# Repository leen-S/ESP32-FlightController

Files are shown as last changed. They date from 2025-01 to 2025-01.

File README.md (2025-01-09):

# ESP32 Flight Controller

## Overview

This repository contains all the necessary files for the **ESP32 Flight Controller** project. Designed for educational and practical purposes, this project showcases how an ESP32 microcontroller can be used to develop a flight controller. It includes firmware, schematics, PCB designs, and manufacturing files to bring the project to life.

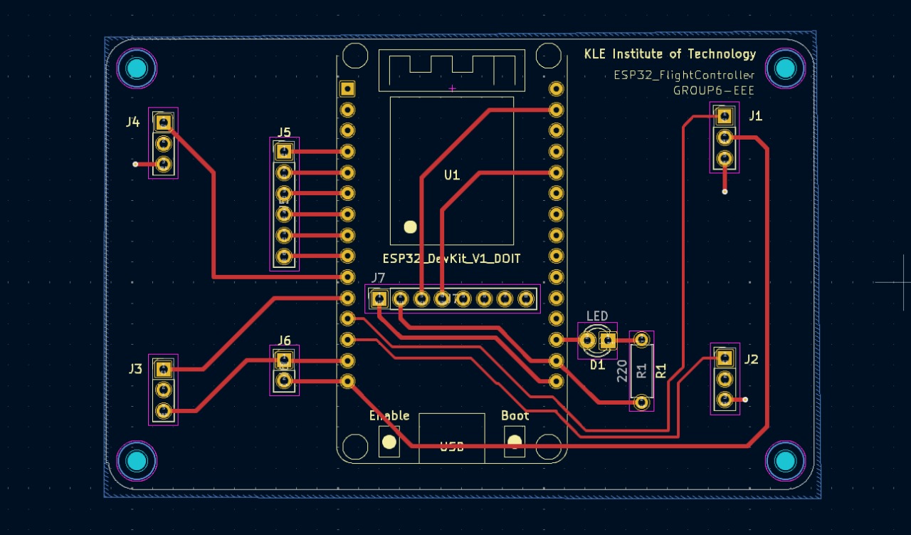
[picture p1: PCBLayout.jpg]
image alt

---

## Repository Structure

### 1. **ESP32-Flight-Controller--main**
This folder contains:
- **Code**: The firmware written for the ESP32 microcontroller to manage and control the drone's operations.
- **Schematics**: Circuit diagrams detailing the hardware connections and design.

### 2. **PCB Designs/KiCAD**
This folder contains:
- **Sketches**: Conceptual sketches of the PCB layout.
- **PCB Layout**: The complete PCB design created using KiCAD.
- **Manufacturing and Gerber Files**: Files required for manufacturing the PCB, including drill files, silkscreen layers, and solder masks.

---

## How to Use

### 1. **Setup and Prerequisites**
- Install the necessary tools:
  - Arduino IDE (or PlatformIO) for uploading the firmware.
  - KiCAD for viewing and editing PCB designs.
- Ensure you have an ESP32 Dev Kit and other necessary components as specified in the schematics.

### 2. **Firmware Installation**
- Navigate to the `ESP32-Flight-Controller--main` folder.
- Open the provided `.ino` or equivalent firmware file in your IDE.
- Configure the project-specific parameters (e.g., pin mappings and calibration values).
- Upload the firmware to the ESP32 using a USB connection.

### 3. **PCB Manufacturing**
- Navigate to the `PCB Designs/KiCAD` folder.
- Use the Gerber files to manufacture the PCB:
  - Upload them to a PCB manufacturer (e.g., JLCPCB, PCBWay).
- Assemble the components as per the provided schematics.

---

## Features
- **ESP32-based Control**: Utilizes the ESP32 microcontroller for real-time flight control.
- **Modular Design**: The project is organized into distinct files for ease of use and modification.
- **Custom PCB**: Designed using KiCAD for a compact and efficient layout.
- **Open Source**: Fully customizable and adaptable for different applications.

---

## Acknowledgment
Special thanks to **@pratikphadte** for making amazing videos.

---

## Contributing
Contributions are welcome! Feel free to:
- Submit bug reports or feature requests via the Issues tab.
- Fork the repository and submit pull requests with improvements.

---

## License
This project is licensed under the [MIT License](LICENSE). You are free to use, modify, and distribute the code and designs with proper attribution.

---

## Contact
For questions or collaboration, reach out via:
- **Email**: neelalohitk@gmail.com
- **LinkedIn**: https://www.linkedin.com/in/neelalohit-korlhalli/

---

Happy Building! 🚀

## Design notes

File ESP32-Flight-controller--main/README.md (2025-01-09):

# ESP32 Flight Controller  

I have chosen ESP32 as a flight controller mainly because of its cost, WiFi & BLE capabilities. Which one can exploit to integrate with ROS. 
---

## Watch Tutorial videos
#### Dorm Flight  
Dorm flight (https://youtu.be/2goVaf8LJQM)

#### Flight Demonstration & few guidelines before building
Flight Demonstration (https://youtu.be/PweCWXNrxg0?si=KJHE-g0SIH3p4Ixf)

#### Understanding PID Controller  
Understanding PID Controller (https://youtu.be/dMRDzicSvXk?si=4SlX_EvzxvCbH7zv)

#### Tuning of PID Controller Gains via ESP32 Webserver WiFi  
Tuning of PID Controller Gains (https://youtu.be/kl3Dlm11AEQ?si=NrJVn8WFx9-ViMtl)

---

## Testing  

Before attempting flight, ensure all components are functioning correctly by testing them individually using the codes provided in the **testing folder**:  

- Use **/ESP32-Flight-controller-/test/reciever_pwm_esp32/reciever_pwm_esp32.ino** to verify the signals from the receiver and transmitter.  
- Use **/ESP32-Flight-controller-/test/measure_angles_from_mpu/measure_angles_from_mpu.ino** to confirm the IMU is measuring angles accurately.  
- Use **/ESP32-Flight-controller-/test/motor_calibration_esp32/motor_calibration_esp32.ino** to calibrate all ESCs and ensure motors are properly synchronized.  
- Use **/ESP32-Flight-controller-/test/Voltage_measurement_esp32/Voltage_measurement_esp32.ino** to validate the voltage sensing circuit. This part is not yet impleneted in the main Flight controller (Can be skipped).

- Use **/workspaces/ESP32-Flight-controller-/test/anglemode_flightcontroller_ver3.1_PID_values_tuning_webserver/anglemode_flightcontroller_ver3.1_PID_values_tuning_webserver.ino** to tune the PID gains of your drone. Do this step when you have calibrated your drone and ensured proper motor direction, propeller direction is as per the hand drawn cirucit diagram in **/ESP32-Flight-controller-/resources/Circuit diagram _HANDDRAWN_ only IMU_01.pdf**

---

## Flying  

Before flying the drone, follow these steps:  

1. **IMU Calibration**  
   - Run the calibration code from the **/ESP32-Flight-controller-/src/Gyro_accelerometer_calibration.ino** to calibrate the IMU. Ensure the quadcopter is on a level surface during this process.  
   - Record the calibrated values generated by the calibration code, check the serial monitor.

2. **Update the Main Flight Code**  
   - Enter the calibrated IMU values into the **/ESP32-Flight-controller-/src/Anglemode_flightcontroller_ver3.1.ino** code's void Setup() with these values before uploading it to the ESP32.  

3. **Tune PID gains** 
    - Refer the PID tuning video in the above YT links and tune your quadcopter, refer the **/ESP32-Flight-controller-/test/anglemode_flightcontroller_ver3.1_PID_values_tuning_webserver/anglemode_flightcontroller_ver3.1_PID_values_tuning_webserver.ino** code for seamless WIFI pid gains tuning. For a F450 frame the PID values should be more or less the same as the values in the original code. For other drone frames it might varry in a slight manner.

3. **Prepare for Flight**  
   - Double-check motor rotations and propeller    orientations as per the schematic.  
   - Ensure all connections are secure.  

5. **Safety First!!!!**
    -The quadcopter motors and propellers possess significant destructive energy. Always:  
    - Conduct initial tests outdoors.  
    - Verify that all propellers are installed in the correct direction and that motor rotations match the schematic.  
    - Recheck motor and propeller functionality before uploading the main flight code.  

5. **You're Ready to fly!**
    - Perform an initial outdoor test for safety.  

---

## References
- [Joop Brooking](https://www.youtube.com/@Joop_Brokking)  
- [Carbon Aeronautics](https://youtube.com/@carbonaeronautics?si=-DZ1Sz5sgNruoJgR)

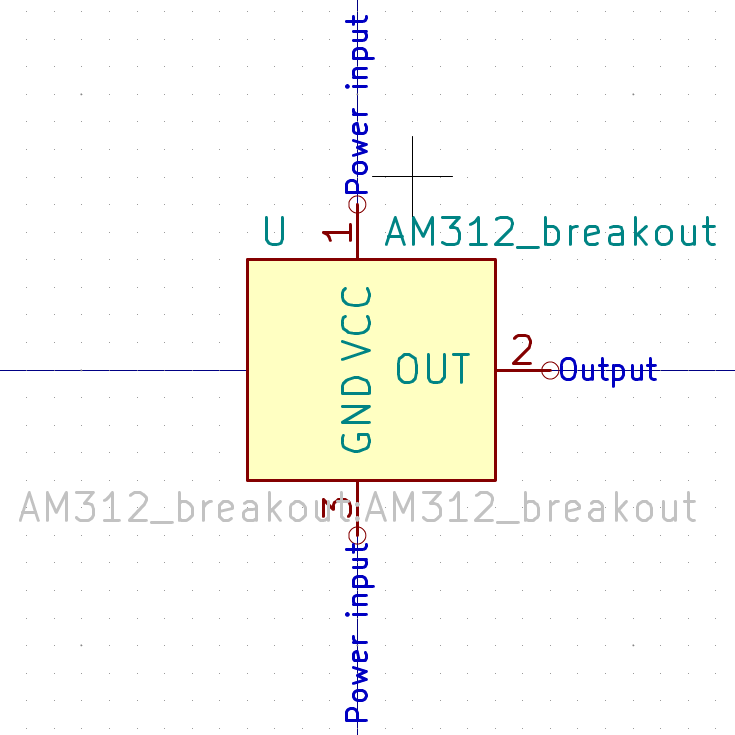
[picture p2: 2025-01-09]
PCB Designs/KiCAD/kicad-master/kicad-master/documentation/aht10_breakout/images/symbol.png

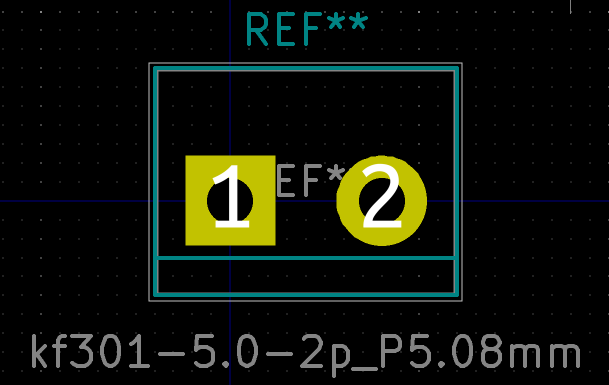
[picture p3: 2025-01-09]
PCB Designs/KiCAD/kicad-master/kicad-master/documentation/kf301_5.0/images/footprint.png

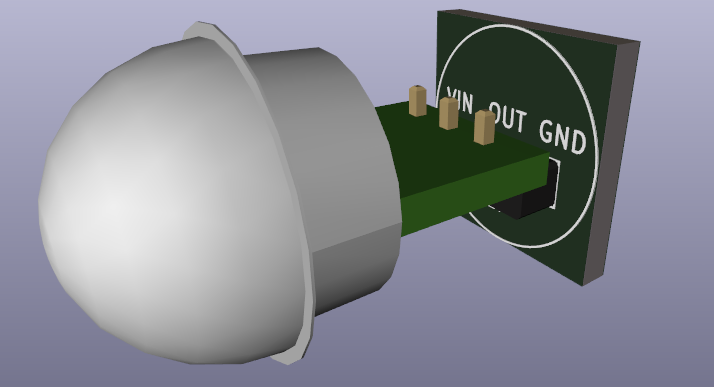
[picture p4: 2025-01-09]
PCB Designs/KiCAD/kicad-master/kicad-master/documentation/am312_breakout/images/3d_view.png

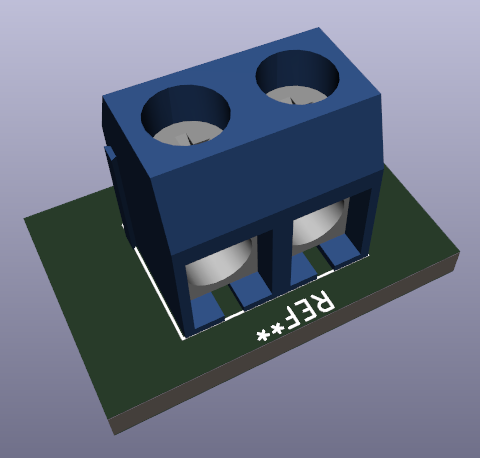
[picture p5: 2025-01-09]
PCB Designs/KiCAD/kicad-master/kicad-master/documentation/kf301_5.0/images/3d_view.png

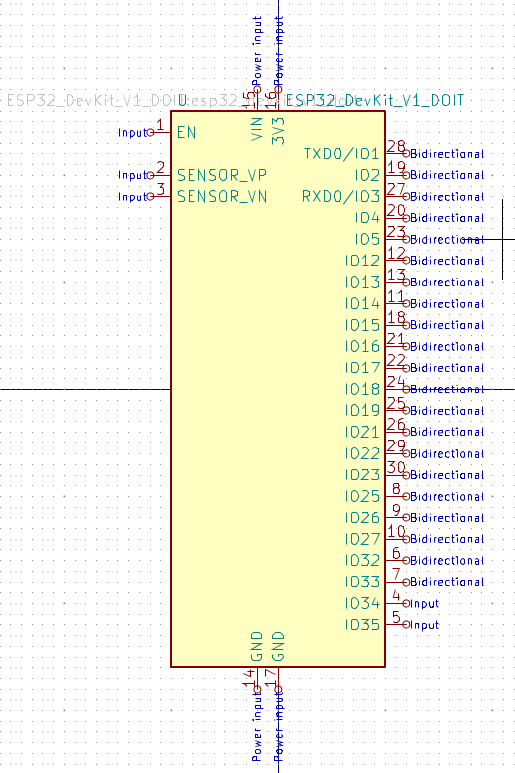
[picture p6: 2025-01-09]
PCB Designs/KiCAD/kicad-master/kicad-master/documentation/esp32_devkit_v1_doit/images/symbol.png

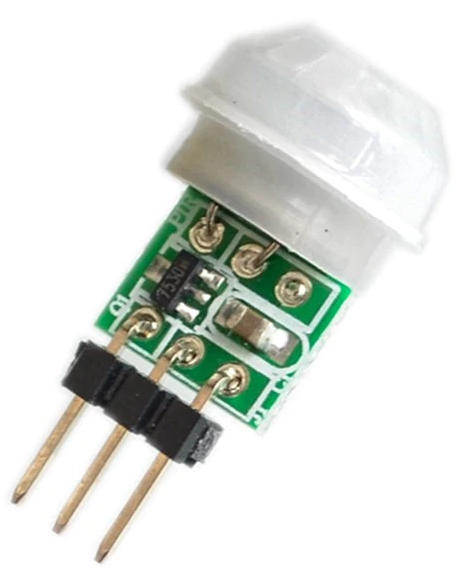
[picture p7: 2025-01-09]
PCB Designs/KiCAD/kicad-master/kicad-master/documentation/am312_breakout/images/picture.jpg

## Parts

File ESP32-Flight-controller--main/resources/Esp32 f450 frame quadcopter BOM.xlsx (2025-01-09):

ESP32 QUADCOPTER BILL OF MATERIALS
Sr No | Category | Item Desc | Qty Reqd | Unit Price(INR) | Total price(INR) | Total Quadcopter Cost(Excluding tools) | 11675
1 | Quadcopter | F450 / Q450 Quadcopter Frame – PCB Version Frame Kit with Integrated PCB – Made in INDIA | 1 | 800 | 800 | Flight contorller cost | 685
2 | Quadcopter | Flysky FS-i6X 2.4GHz 6CH AFHDS 2A RC Transmitter With FS-iA10B 2.4GHz 10CH Receiver | 1 | 4800 | 4800
3 | Quadcopter | A2212 1000 KV BLDC Brushless DC Motor with SimonK 30A ESC | 4 | 710 | 2840
4 | Quadcopter | Orange HD Propellers 8045(8X4.5) ABS Black 1CW+1CCW-1pair | 3 | 100 | 300
5 | Quadcopter | Orange 11.1V 2200mAh 40C 3S Lithium Polymer Battery Pack | 1 | 1800 | 1800
6 | Quadcopter | Lipo Battery Charger | Battery Balancer Charger 7.4-11.1V RC Pro Compact Charger B3AC | 1 | 450 | 450
7 | Flight controller | MPU-6050 3-Axis Accelerometer and Gyro Sensor | 1 | 115 | 115
8 | Flight controller | ESP32 DEV KIT DO IT 1 | 1 | 400 | 400
9 | Flight controller | 5 x 7 cm Universal PCB Prototype Board | 1 | 30 | 30
10 | Flight controller | LED | 1 | 10 | 10
11 | Flight controller | Resistors 220 ohms | 1 | 10 | 10
12 | Flight controller | Single strand wire (1m) | 1 | 40 | 40
13 | Flight controller | Berg pin male strip | 2 | 20 | 40
14 | Flight controller | Berg pin female strip | 2 | 20 | 40
15 | Tools & adhesives | Soldering Iron | 1 | 300 | 300
16 | Tools & adhesives | Soldering wire | 1 | 50 | 50
17 | Tools & adhesives | Soldering flux | 1 | 20 | 20
18 | Tools & adhesives | Double sided tape roll | 1 | 50 | 50
19 | Tools & adhesives | Zipties (15cm long) packet | 1 | 60 | 60
20 | Tools & adhesives | Wire cutter | 1 | 50 | 50
21 | Tools & adhesives | Insulation tape | 1 | 20 | 20
22 | Tools & adhesives | Allen Key for M2,M3 & M4 Grub Screw | 1 | 40 | 40

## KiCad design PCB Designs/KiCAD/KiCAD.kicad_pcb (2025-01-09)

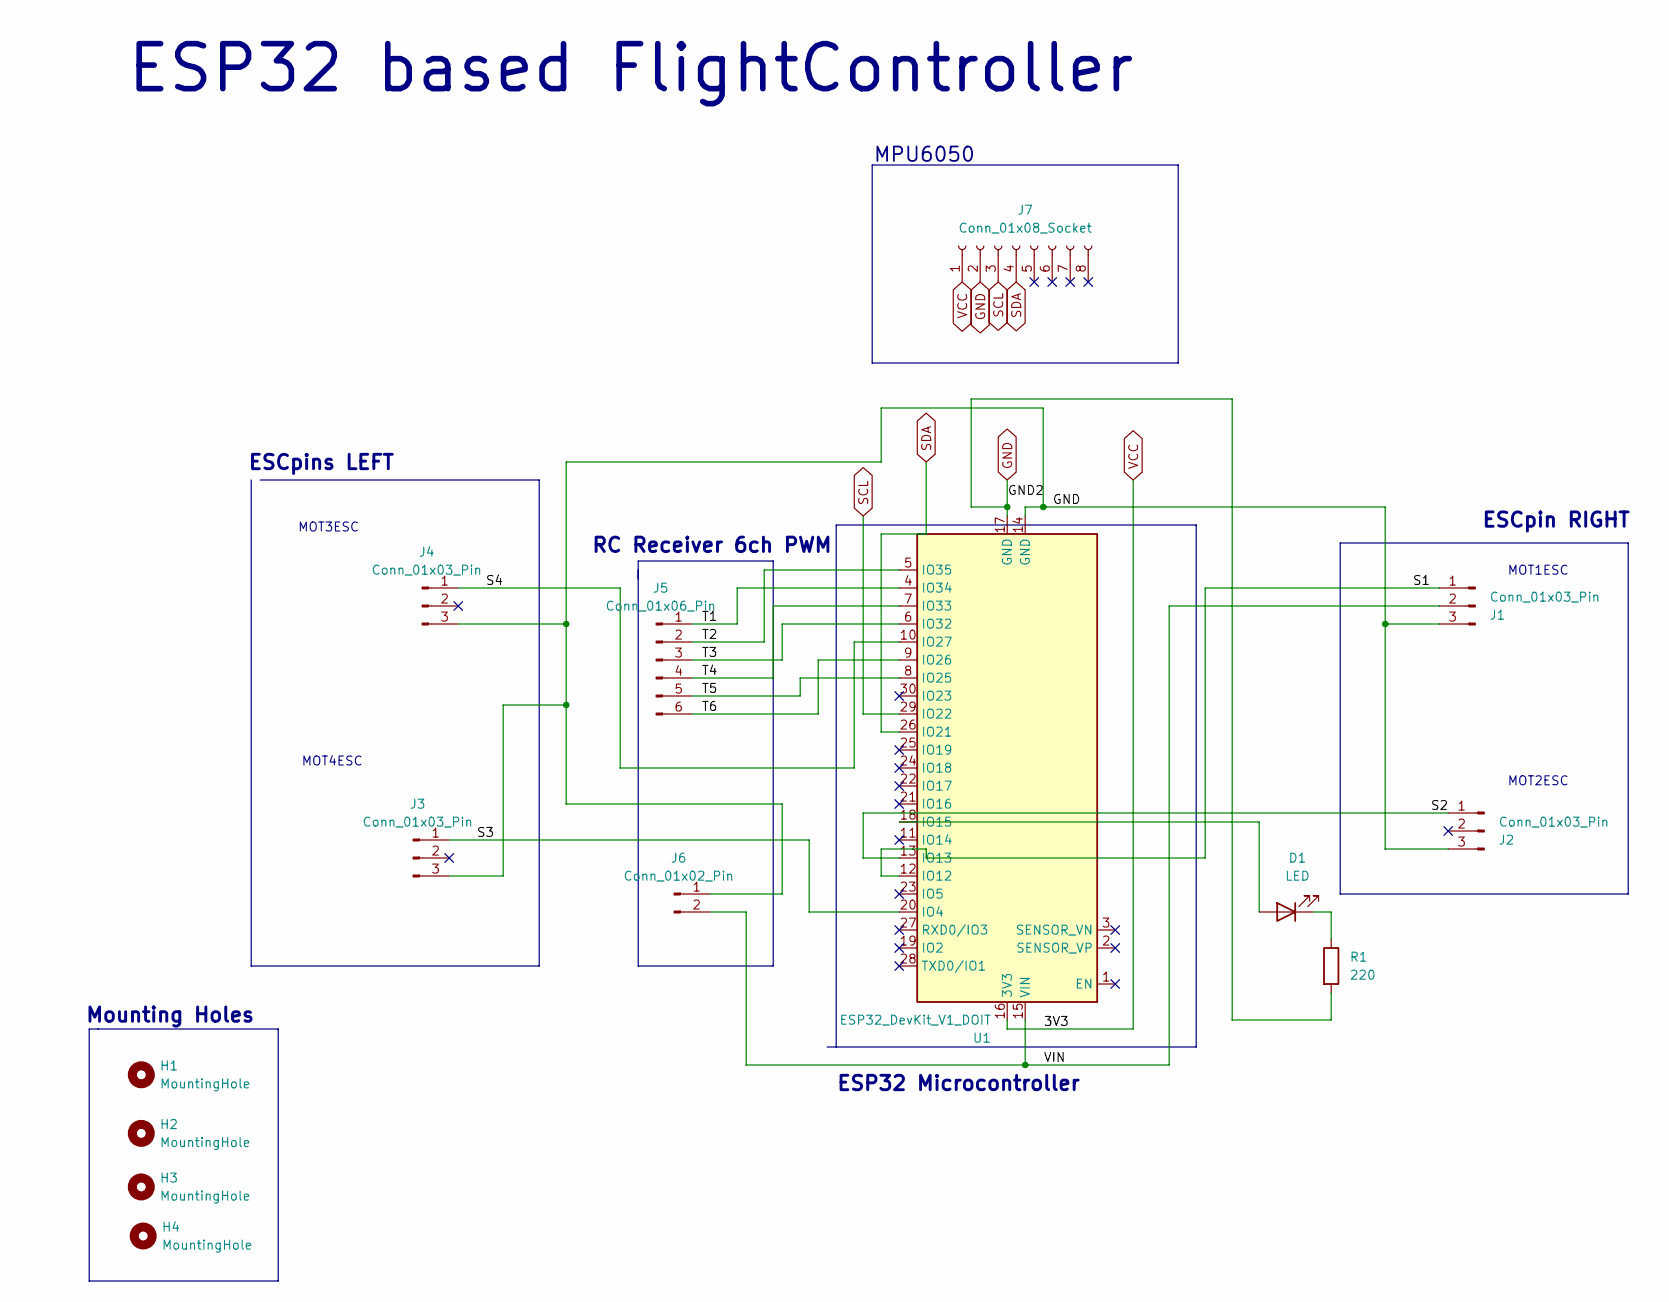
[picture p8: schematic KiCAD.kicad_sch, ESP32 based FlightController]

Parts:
D1: LED; LED_D3.0mm
H1, H2, H3, H4: MountingHole; MountingHole_2.2mm_M2
J1, J2, J3, J4: Conn_01x03_Pin; PinHeader_1x03_P2.54mm_Vertical
J5: Conn_01x06_Pin; PinHeader_1x06_P2.54mm_Vertical
J6: Conn_01x02_Pin; PinHeader_1x02_P2.54mm_Vertical
J7: Conn_01x08_Socket; PinSocket_1x08_P2.54mm_Vertical
R1: 220; R_Axial_DIN0207_L6.3mm_D2.5mm_P7.62mm_Horizontal
U1: ESP32_DevKit_V1_DOIT; esp32_devkit_v1_doit

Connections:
/S1: J1.1, U1.12 (IO12)
/S2: J2.1, U1.13 (IO13)
/S3: J3.1, U1.20 (IO4)
/S4: J4.1, U1.10 (IO27)
/T1: J5.1, U1.4 (IO34)
/T2: J5.2, U1.5 (IO35)
/T3: J5.3, U1.6 (IO32)
/T4: J5.4, U1.7 (IO33)
/T5: J5.5, U1.8 (IO25)
/T6: J5.6, U1.9 (IO26)
/VIN: J1.2, J6.2, U1.15 (VIN)
GND: J1.3, J2.3, J3.3, J4.3, J6.1, J7.2, R1.2, U1.14 (GND), U1.17 (GND)
unnamed: D1.2 (A), U1.18 (IO15)
unnamed: D1.1 (K), R1.1
SCL: J7.3, U1.29 (IO22)
SDA: J7.4, U1.26 (IO21)
VCC: J7.1, U1.16 (3V3)

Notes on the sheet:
ESP32 based FlightController
RC Receiver 6ch PWM
ESP32 Microcontroller
MOT1ESC
Mounting Holes
MPU6050
MOT4ESC
ESCpin RIGHT
ESCpins LEFT
MOT3ESC
MOT2ESC

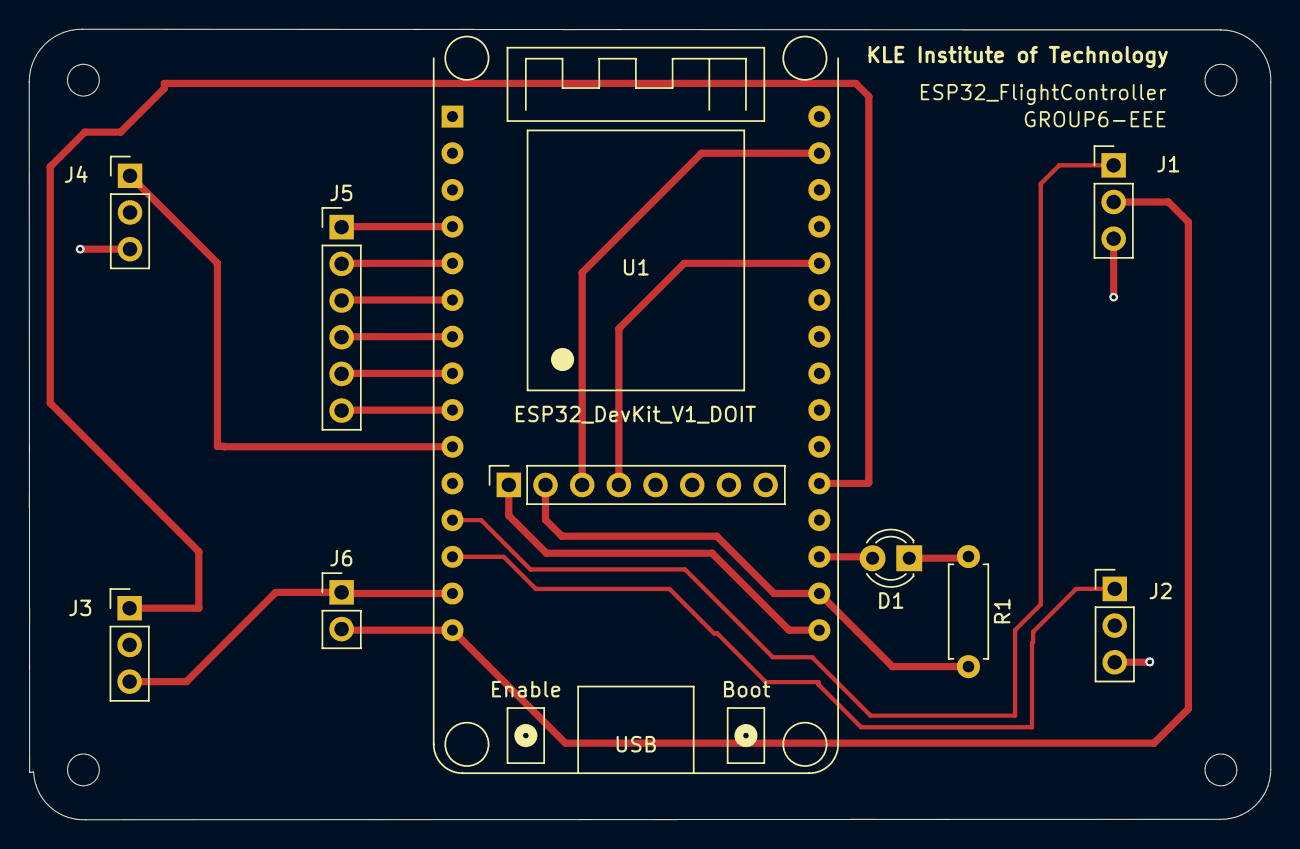
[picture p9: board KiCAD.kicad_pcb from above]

Board: 2 copper layers, 86.0 x 54.7 mm, 14 parts (0 on the bottom side), 17 nets.

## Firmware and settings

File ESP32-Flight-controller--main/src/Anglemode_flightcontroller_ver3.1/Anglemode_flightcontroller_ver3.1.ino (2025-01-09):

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


#include <Wire.h>
#include <ESP32Servo.h> // Change to the standard Servo library for ESP32

volatile float RatePitch, RateRoll, RateYaw;
float RateCalibrationPitch, RateCalibrationRoll, RateCalibrationYaw,AccXCalibration,AccYCalibration,AccZCalibration;

int ESCfreq=500;
float PAngleRoll=2; float PAnglePitch=PAngleRoll;
float IAngleRoll=0.5; float IAnglePitch=IAngleRoll;
float DAngleRoll=0.007; float DAnglePitch=DAngleRoll;

float PRateRoll = 0.625;
float IRateRoll = 2.1;
float DRateRoll = 0.0088;

float PRatePitch = PRateRoll;
float IRatePitch = IRateRoll;
float DRatePitch = DRateRoll;

float PRateYaw = 4;
float IRateYaw = 3;
float DRateYaw = 0;

uint32_t LoopTimer;
float t=0.004;      //time cycle

Servo mot1;
Servo mot2;
Servo mot3;
Servo mot4;

const int mot1_pin = 13;
const int mot2_pin = 12;
const int mot3_pin = 4; //is 14 for some designed FC on perforated baords
const int mot4_pin = 27;

volatile uint32_t current_time;
volatile uint32_t last_channel_1 = 0;
volatile uint32_t last_channel_2 = 0;
volatile uint32_t last_channel_3 = 0;
volatile uint32_t last_channel_4 = 0;
volatile uint32_t last_channel_5 = 0;
volatile uint32_t last_channel_6 = 0;
volatile uint32_t timer_1;
volatile uint32_t timer_2;
volatile uint32_t timer_3;
volatile uint32_t timer_4;
volatile uint32_t timer_5;
volatile uint32_t timer_6;
volatile int ReceiverValue[6]; // Increase the array size to 6 for Channel 1 to Channel 6
const int channel_1_pin = 34;
const int channel_2_pin = 35;
const int channel_3_pin = 32;
const int channel_4_pin = 33;
const int channel_5_pin = 25;
const int channel_6_pin = 26;

volatile float PtermRoll;
volatile float ItermRoll;
volatile float DtermRoll;
volatile float PIDOutputRoll;
volatile float PtermPitch;
volatile float ItermPitch;
volatile float DtermPitch;
volatile float PIDOutputPitch;
volatile float PtermYaw;
volatile float ItermYaw;
volatile float DtermYaw;
volatile float PIDOutputYaw;
volatile float KalmanGainPitch;
volatile float KalmanGainRoll;

int ThrottleIdle = 1170;
int ThrottleCutOff = 1000;

volatile float DesiredRateRoll, DesiredRatePitch, DesiredRateYaw;
volatile float ErrorRateRoll, ErrorRatePitch, ErrorRateYaw;
volatile float InputRoll, InputThrottle, InputPitch, InputYaw;
volatile float PrevErrorRateRoll, PrevErrorRatePitch, PrevErrorRateYaw;
volatile float PrevItermRateRoll, PrevItermRatePitch, PrevItermRateYaw;
volatile float PIDReturn[] = {0, 0, 0};

//Kalman filters for angle mode
volatile float AccX, AccY, AccZ;
volatile float AngleRoll, AnglePitch;
volatile float KalmanAngleRoll=0, KalmanUncertaintyAngleRoll=2*2;
volatile float KalmanAnglePitch=0, KalmanUncertaintyAnglePitch=2*2;
volatile float Kalman1DOutput[]={0,0};
volatile float DesiredAngleRoll, DesiredAnglePitch;
volatile float ErrorAngleRoll, ErrorAnglePitch;
volatile float PrevErrorAngleRoll, PrevErrorAnglePitch;
volatile float PrevItermAngleRoll, PrevItermAnglePitch;


float complementaryAngleRoll = 0.0f;
float complementaryAnglePitch = 0.0f;

volatile float MotorInput1, MotorInput2, MotorInput3, MotorInput4;

void kalman_1d(float KalmanState, float KalmanUncertainty, float KalmanInput, float KalmanMeasurement) {
  KalmanState=KalmanState + (t*KalmanInput);
  KalmanUncertainty=KalmanUncertainty + (t*t*4*4); //here 4 is the vairnece of IMU i.e 4 deg/s
  float KalmanGain=KalmanUncertainty * 1/(1*KalmanUncertainty + 3 * 3); //std deviation of error is 3 deg
  KalmanState=KalmanState+KalmanGain * (KalmanMeasurement-KalmanState);
  KalmanUncertainty=(1-KalmanGain) * KalmanUncertainty;
  Kalman1DOutput[0]=KalmanState; 
  Kalman1DOutput[1]=KalmanUncertainty;
}



void channelInterruptHandler()
{
current_time = micros(); if (digitalRead(channel_1_pin)) { if (last_channel_1 == 0) { last_channel_1 = 1; timer_1 = current_time; } } else if (last_channel_1 == 1) { last_channel_1 = 0; ReceiverValue[0] = current_time - timer_1; } 
if (digitalRead(channel_2_pin)) { if (last_channel_2 == 0) { last_channel_2 = 1; timer_2 = current_time; } } else if (last_channel_2 == 1) { last_channel_2 = 0; ReceiverValue[1] = current_time - timer_2; } 
if (digitalRead(channel_3_pin)) { if (last_channel_3 == 0) { last_channel_3 = 1; timer_3 = current_time; } } else if (last_channel_3 == 1) { last_channel_3 = 0; ReceiverValue[2] = current_time - timer_3; } 
if (digitalRead(channel_4_pin)) { if (last_channel_4 == 0) { last_channel_4 = 1; timer_4 = current_time; } } else if (last_channel_4 == 1) { last_channel_4 = 0; ReceiverValue[3] = current_time - timer_4; } 
if (digitalRead(channel_5_pin)) { if (last_channel_5 == 0) { last_channel_5 = 1; timer_5 = current_time; } } else if (last_channel_5 == 1) { last_channel_5 = 0; ReceiverValue[4] = current_time - timer_5; } 
if (digitalRead(channel_6_pin)) { if (last_channel_6 == 0) { last_channel_6 = 1; timer_6 = current_time; } } else if (last_channel_6 == 1) { last_channel_6 = 0; ReceiverValue[5] = current_time - timer_6; }
}

void gyro_signals(void)
{
  Wire.beginTransmission(0x68);
  Wire.write(0x1A);
  Wire.write(0x03);
  Wire.endTransmission();
  Wire.beginTransmission(0x68);
  Wire.write(0x1C);
  Wire.write(0x10);
  Wire.endTransmission();
  Wire.beginTransmission(0x68);
  Wire.write(0x3B);
  Wire.endTransmission(); 
  Wire.requestFrom(0x68,6);
  int16_t AccXLSB = Wire.read() << 8 | Wire.read();
  int16_t AccYLSB = Wire.read() << 8 | Wire.read();
  int16_t AccZLSB = Wire.read() << 8 | Wire.read();
  Wire.beginTransmission(0x68);
  Wire.write(0x1B); 
  Wire.write(0x8);
  Wire.endTransmission();                                                   
  Wire.beginTransmission(0x68);
  Wire.write(0x43);
  Wire.endTransmission();
  Wire.requestFrom(0x68,6);
  int16_t GyroX=Wire.read()<<8 | Wire.read();
  int16_t GyroY=Wire.read()<<8 | Wire.read();
  int16_t GyroZ=Wire.read()<<8 | Wire.read();
  RateRoll=(float)GyroX/65.5;
  RatePitch=(float)GyroY/65.5;
  RateYaw=(float)GyroZ/65.5;
  AccX=(float)AccXLSB/4096;
  AccY=(float)AccYLSB/4096;
  AccZ=(float)AccZLSB/4096;
  AngleRoll=atan(AccY/sqrt(AccX*AccX+AccZ*AccZ))*57.29; //*1/(3.142/180);
  AnglePitch=-atan(AccX/sqrt(AccY*AccY+AccZ*AccZ))*57.29;
}

void pid_equation(float Error, float P, float I, float D, float PrevError, float PrevIterm)
{
  float Pterm = P * Error;
  float Iterm = PrevIterm +( I * (Error + PrevError) * (t/2));
  if (Iterm > 400)
  {
    Iterm = 400;
  }
  else if (Iterm < -400)
  {
  Iterm = -400;
  }
  float Dterm = D *( (Error - PrevError)/t);
  float PIDOutput = Pterm + Iterm + Dterm;
  if (PIDOutput > 400)
  {
    PIDOutput = 400;
  }
  else if (PIDOutput < -400)
  {
    PIDOutput = -400;
  }
  PIDReturn[0] = PIDOutput;
  PIDReturn[1] = Error;
  PIDReturn[2] = Iterm;
}

void setup(void) {
  
Serial.begin(115200);


int led_time=100;
 pinMode(15, OUTPUT);
  digitalWrite(15, LOW);
  delay(led_time);
  digitalWrite(15, HIGH);
  delay(led_time);
  digitalWrite(15, LOW);
  delay(led_time);
  digitalWrite(15, HIGH);
  delay(led_time);
  digitalWrite(15, LOW);
  delay(led_time);
  digitalWrite(15, HIGH);
  delay(led_time);
  digitalWrite(15, LOW);
  delay(led_time);
  digitalWrite(15, HIGH);
  delay(led_time);
  digitalWrite(15, LOW);
  delay(led_time);


  pinMode(channel_1_pin, INPUT_PULLUP);
  pinMode(channel_2_pin, INPUT_PULLUP);
  pinMode(channel_3_pin, INPUT_PULLUP);
  pinMode(channel_4_pin, INPUT_PULLUP);
  pinMode(channel_5_pin, INPUT_PULLUP);
  pinMode(channel_6_pin, INPUT_PULLUP);

  attachInterrupt(digitalPinToInterrupt(channel_1_pin), channelInterruptHandler, CHANGE);
  attachInterrupt(digitalPinToInterrupt(channel_2_pin), channelInterruptHandler, CHANGE);
  attachInterrupt(digitalPinToInterrupt(channel_3_pin), channelInterruptHandler, CHANGE);
  attachInterrupt(digitalPinToInterrupt(channel_4_pin), channelInterruptHandler, CHANGE);
  attachInterrupt(digitalPinToInterrupt(channel_5_pin), channelInterruptHandler, CHANGE);
  attachInterrupt(digitalPinToInterrupt(channel_6_pin), channelInterruptHandler, CHANGE);
  delay(100);
  
  Wire.setClock(400000);
  Wire.begin();
  delay(250);
  Wire.beginTransmission(0x68);
  Wire.write(0x6B);
  Wire.write(0x00);
  Wire.endTransmission();

 	ESP32PWM::allocateTimer(0);
	ESP32PWM::allocateTimer(1);
	ESP32PWM::allocateTimer(2);
	ESP32PWM::allocateTimer(3);

  delay(1000);
  mot1.attach(mot1_pin,1000,2000);
  delay(1000);
  mot1.setPeriodHertz(ESCfreq);
  delay(100);
  mot2.attach(mot2_pin,1000,2000);
  delay(1000);
  mot2.setPeriodHertz(ESCfreq);
  delay(100);
  mot3.attach(mot3_pin,1000,2000);
  delay(1000);
  mot3.setPeriodHertz(ESCfreq);
  delay(100);
  mot4.attach(mot4_pin,1000,2000);
  delay(1000);
  mot4.setPeriodHertz(ESCfreq);
  delay(100);

  mot1.writeMicroseconds(1000);
  mot2.writeMicroseconds(1000);
  mot3.writeMicroseconds(1000);
  mot4.writeMicroseconds(1000);
   delay(500);
  digitalWrite(15, LOW);
  digitalWrite(15, HIGH);
  delay(500);
  digitalWrite(15, LOW);
  delay(500);


RateCalibrationRoll=0.27;
RateCalibrationPitch=-0.85;
RateCalibrationYaw=-2.09;
AccXCalibration=0.03;
AccYCalibration=0.01;
AccZCalibration=-0.07;

LoopTimer = micros();

}

void loop(void) {


  //enter your loop code here
Wire.beginTransmission(0x68);
  Wire.write(0x1A);
  Wire.write(0x05);
  Wire.endTransmission();
  Wire.beginTransmission(0x68);
  Wire.write(0x1C);
  Wire.write(0x10);
  Wire.endTransmission();
  Wire.beginTransmission(0x68);
  Wire.write(0x3B);
  Wire.endTransmission(); 
  Wire.requestFrom(0x68,6);
  int16_t AccXLSB = Wire.read() << 8 | Wire.read();
  int16_t AccYLSB = Wire.read() << 8 | Wire.read();
  int16_t AccZLSB = Wire.read() << 8 | Wire.read();
  Wire.beginTransmission(0x68);
  Wire.write(0x1B); 
  Wire.write(0x8);
  Wire.endTransmission();                                                   
  Wire.beginTransmission(0x68);
  Wire.write(0x43);
  Wire.endTransmission();
  Wire.requestFrom(0x68,6);
  int16_t GyroX=Wire.read()<<8 | Wire.read();
  int16_t GyroY=Wire.read()<<8 | Wire.read();
  int16_t GyroZ=Wire.read()<<8 | Wire.read();
  RateRoll=(float)GyroX/65.5;
  RatePitch=(float)GyroY/65.5;
  RateYaw=(float)GyroZ/65.5;
  AccX=(float)AccXLSB/4096;
  AccY=(float)AccYLSB/4096;
  AccZ=(float)AccZLSB/4096;


RateRoll -= RateCalibrationRoll;
RatePitch -= RateCalibrationPitch;
RateYaw -= RateCalibrationYaw;

AccX -= AccXCalibration ;
AccY -= AccYCalibration ;
AccZ -= AccZCalibration;

  AngleRoll=atan(AccY/sqrt(AccX*AccX+AccZ*AccZ))*57.29;
  AnglePitch=-atan(AccX/sqrt(AccY*AccY+AccZ*AccZ))*57.29;

// // Inlined Kalman Filter computation in the loop
// KalmanAngleRoll += t * RateRoll;
// KalmanUncertaintyAngleRoll += t * t * 16; // Variance of IMU (4 deg/s) squared
// KalmanGainRoll = KalmanUncertaintyAngleRoll / (KalmanUncertaintyAngleRoll + 9); // Error variance (3 deg) squared
// KalmanAngleRoll += KalmanGainRoll * (AngleRoll - KalmanAngleRoll);
// KalmanUncertaintyAngleRoll *= (1 - KalmanGainRoll);

// // Set output for Roll Kalman
// Kalman1DOutput[0] = KalmanAngleRoll;
// Kalman1DOutput[1] = KalmanUncertaintyAngleRoll;

// // Inlined Kalman Filter computation for Pitch
// KalmanAnglePitch += t * RatePitch;
// KalmanUncertaintyAnglePitch += t * t * 16; // Variance of IMU (4 deg/s) squared
// KalmanGainPitch = KalmanUncertaintyAnglePitch / (KalmanUncertaintyAnglePitch + 9); // Error variance (3 deg) squared
// KalmanAnglePitch += KalmanGainPitch * (AnglePitch - KalmanAnglePitch);
// KalmanUncertaintyAnglePitch *= (1 - KalmanGainPitch);

// // Set output for Pitch Kalman
// Kalman1DOutput[0] = KalmanAnglePitch;
// Kalman1DOutput[1] = KalmanUncertaintyAnglePitch;

// KalmanAngleRoll = (KalmanAngleRoll > 20) ? 20 : ((KalmanAngleRoll < -20) ? -20 : KalmanAngleRoll);
// KalmanAnglePitch = (KalmanAnglePitch > 20) ? 20 : ((KalmanAnglePitch < -20) ? -20 : KalmanAnglePitch);


complementaryAngleRoll=0.991*(complementaryAngleRoll+RateRoll*t) + 0.009*AngleRoll;
complementaryAnglePitch=0.991*(complementaryAnglePitch+RatePitch*t) + 0.009*AnglePitch;
// Clamping complementary filter roll angle to ±20 degrees
complementaryAngleRoll = (complementaryAngleRoll > 20) ? 20 : ((complementaryAngleRoll < -20) ? -20 : complementaryAngleRoll);
complementaryAnglePitch = (complementaryAnglePitch > 20) ? 20 : ((complementaryAnglePitch < -20) ? -20 : complementaryAnglePitch);



DesiredAngleRoll=0.1*(ReceiverValue[0]-1500);
DesiredAnglePitch=0.1*(ReceiverValue[1]-1500);
InputThrottle=ReceiverValue[2];
DesiredRateYaw=0.15*(ReceiverValue[3]-1500);


// Inlined PID equation for Roll
ErrorAngleRoll = DesiredAngleRoll - complementaryAngleRoll;
PtermRoll = PAngleRoll * ErrorAngleRoll;
ItermRoll = PrevItermAngleRoll + (IAngleRoll * (ErrorAngleRoll + PrevErrorAngleRoll) * (t / 2));
ItermRoll = (ItermRoll > 400) ? 400 : ((ItermRoll < -400) ? -400 : ItermRoll);
DtermRoll = DAngleRoll * ((ErrorAngleRoll - PrevErrorAngleRoll) / t);
PIDOutputRoll = PtermRoll + ItermRoll + DtermRoll;
PIDOutputRoll = (PIDOutputRoll > 400) ? 400 : ((PIDOutputRoll < -400) ? -400 : PIDOutputRoll);
DesiredRateRoll = PIDOutputRoll;
PrevErrorAngleRoll = ErrorAngleRoll;
PrevItermAngleRoll = ItermRoll;

ErrorAnglePitch = DesiredAnglePitch - complementaryAnglePitch;
PtermPitch = PAnglePitch * ErrorAnglePitch;
ItermPitch = PrevItermAnglePitch + (IAnglePitch * (ErrorAnglePitch + PrevErrorAnglePitch) * (t / 2));
ItermPitch = (ItermPitch > 400) ? 400 : ((ItermPitch < -400) ? -400 : ItermPitch);
DtermPitch = DAnglePitch * ((ErrorAnglePitch - PrevErrorAnglePitch) / t);
PIDOutputPitch = PtermPitch + ItermPitch + DtermPitch;
PIDOutputPitch = (PIDOutputPitch > 400) ? 400 : ((PIDOutputPitch < -400) ? -400 : PIDOutputPitch);
DesiredRatePitch = PIDOutputPitch;
PrevErrorAnglePitch = ErrorAnglePitch;
PrevItermAnglePitch = ItermPitch;

// Compute errors
ErrorRateRoll = DesiredRateRoll - RateRoll;
ErrorRatePitch = DesiredRatePitch - RatePitch;
ErrorRateYaw = DesiredRateYaw - RateYaw;

// Roll Axis PID
PtermRoll = PRateRoll * ErrorRateRoll;
ItermRoll = PrevItermRateRoll + (IRateRoll * (ErrorRateRoll + PrevErrorRateRoll) * (t / 2));
ItermRoll = (ItermRoll > 400) ? 400 : ((ItermRoll < -400) ? -400 : ItermRoll);
DtermRoll = DRateRoll * ((ErrorRateRoll - PrevErrorRateRoll) / t);
PIDOutputRoll = PtermRoll + ItermRoll + DtermRoll;
PIDOutputRoll = (PIDOutputRoll > 400) ? 400 : ((PIDOutputRoll < -400) ? -400 : PIDOutputRoll);

// Update output and previous values for Roll
InputRoll = PIDOutputRoll;
PrevErrorRateRoll = ErrorRateRoll;
PrevItermRateRoll = ItermRoll;

// Pitch Axis PID
PtermPitch = PRatePitch * ErrorRatePitch;
ItermPitch = PrevItermRatePitch + (IRatePitch * (ErrorRatePitch + PrevErrorRatePitch) * (t / 2));
ItermPitch = (ItermPitch > 400) ? 400 : ((ItermPitch < -400) ? -400 : ItermPitch);
DtermPitch = DRatePitch * ((ErrorRatePitch - PrevErrorRatePitch) / t);
PIDOutputPitch = PtermPitch + ItermPitch + DtermPitch;
PIDOutputPitch = (PIDOutputPitch > 400) ? 400 : ((PIDOutputPitch < -400) ? -400 : PIDOutputPitch);

// Update output and previous values for Pitch
InputPitch = PIDOutputPitch;
PrevErrorRatePitch = ErrorRatePitch;
PrevItermRatePitch = ItermPitch;

// Yaw Axis PID
PtermYaw = PRateYaw * ErrorRateYaw;
ItermYaw = PrevItermRateYaw + (IRateYaw * (ErrorRateYaw + PrevErrorRateYaw) * (t / 2));
ItermYaw = (ItermYaw > 400) ? 400 : ((ItermYaw < -400) ? -400 : ItermYaw);  // Clamp ItermYaw to [-400, 400]
DtermYaw = DRateYaw * ((ErrorRateYaw - PrevErrorRateYaw) / t);
PIDOutputYaw = PtermYaw + ItermYaw + DtermYaw;
PIDOutputYaw = (PIDOutputYaw > 400) ? 400 : ((PIDOutputYaw < -400) ? -400 : PIDOutputYaw);  // Clamp PIDOutputYaw to [-400, 400]


// Update output and previous values for Yaw
InputYaw = PIDOutputYaw;
PrevErrorRateYaw = ErrorRateYaw;
PrevItermRateYaw = ItermYaw;


  if (InputThrottle > 1800)
  {
    InputThrottle = 1800;
  }

  
  MotorInput1 =  (InputThrottle - InputRoll - InputPitch - InputYaw); // front right - counter clockwise
  MotorInput2 =  (InputThrottle - InputRoll + InputPitch + InputYaw); // rear right - clockwise
  MotorInput3 =  (InputThrottle + InputRoll + InputPitch - InputYaw); // rear left  - counter clockwise
  MotorInput4 =  (InputThrottle + InputRoll - InputPitch + InputYaw); //front left - clockwise


  if (MotorInput1 > 2000)
  {
    MotorInput1 = 1999;
  }

  if (MotorInput2 > 2000)
  {
    MotorInput2 = 1999;
  }

  if (MotorInput3 > 2000)
  {
    MotorInput3 = 1999;
  }

  if (MotorInput4 > 2000)
  {
    MotorInput4 = 1999;
  }


// int ThrottleIdle = 1150;
// int ThrottleCutOff = 1000;
  if (MotorInput1 < ThrottleIdle)
  {
    MotorInput1 = ThrottleIdle;
  }
  if (MotorInput2 < ThrottleIdle)
  {
    MotorInput2 = ThrottleIdle;
  }
  if (MotorInput3 < ThrottleIdle)
  {
    MotorInput3 = ThrottleIdle;
  }
  if (MotorInput4 < ThrottleIdle)
  {
    MotorInput4 = ThrottleIdle;
  }

 if (ReceiverValue[2] < 1030 ) // dont Arm the motors
  {
   
  MotorInput1 = ThrottleCutOff;
  MotorInput2 = ThrottleCutOff;
  MotorInput3 = ThrottleCutOff;
  MotorInput4 = ThrottleCutOff;

  PrevErrorRateRoll=0; PrevErrorRatePitch=0; PrevErrorRateYaw=0;
  PrevItermRateRoll=0; PrevItermRatePitch=0; PrevItermRateYaw=0;
  PrevErrorAngleRoll=0; PrevErrorAnglePitch=0;    
  PrevItermAngleRoll=0; PrevItermAnglePitch=0;
  
  }

// Calculate motor control values directly
mot1.writeMicroseconds(MotorInput1);
mot2.writeMicroseconds(MotorInput2);
mot3.writeMicroseconds(MotorInput3);
mot4.writeMicroseconds(MotorInput4);



//Reciever signals
  // Serial.print(ReceiverValue[0]);
  // Serial.print(" ");
  // Serial.print(ReceiverValue[1]);
  // Serial.print(" ");
  // Serial.print(ReceiverValue[2]);
  // Serial.print(" ");
  // Serial.print(ReceiverValue[3]);
  // Serial.print(" ");
 
  // Serial.print(ReceiverValue[4]);
  // Serial.print(" - ");
  // Serial.print(ReceiverValue[5]);
  // Serial.print(" - ");

// //Motor PWMs in us
//   Serial.print("MotVals-");
  // Serial.print(MotorInput1);
  // Serial.print("  ");
  // Serial.print(MotorInput2);
  // Serial.print("  ");
  // Serial.print(MotorInput3);
  // Serial.print("  ");
  // Serial.print(MotorInput4);
  // Serial.println(" ");

// //Reciever translated rates
//   Serial.print(DesiredRateRoll);
//   Serial.print("  ");
//   Serial.print(DesiredRatePitch);
//   Serial.print("  ");
//   Serial.print(DesiredRateYaw);
//   Serial.print(" -- ");

// // //IMU values
  // Serial.print("Acc values: ");
  // Serial.print("AccX:");
  // Serial.print(AccX);
  // Serial.print("  ");
  // Serial.print("AccY:");
  // Serial.print(AccY);
  // Serial.print("  ");
  // Serial.print("AccZ:");
  // Serial.print(AccZ);
  // Serial.print(" -- ");
  // Print the gyroscope values
  // Serial.print("Gyro values: ");
  // Serial.print(RateRoll);
  // Serial.print("  ");
  // Serial.print(RatePitch);
  // Serial.print("  ");
  // Serial.print(RateYaw);
  // Serial.print("  ");
  // Serial.print(" -- ");

//PID outputs
// Serial.print("PID O/P ");
// Serial.print(InputPitch);
//   Serial.print("  ");
// Serial.print(InputRoll);
//   Serial.print("  ");
// Serial.print(InputYaw);
//   Serial.print(" -- ");

//Angles from MPU
  // Serial.print("AngleRoll:");
  // Serial.print(AngleRoll);
  // //serial.print("  ");
  //   Serial.print("AnglePitch:");
  // Serial.print(AnglePitch);

  // Serial.print("KalmanAngleRoll:");
  // Serial.print(KalmanAngleRoll);
  // //serial.print("  ");
  //   Serial.print("KalmanAnglePitch:");
  // Serial.print(KalmanAnglePitch);

  // Serial.print("ComplementaryAngleRoll: ");
  // Serial.print(complementaryAngleRoll);
  // Serial.print("ComplementaryAnglePitch: ");
  // Serial.print(complementaryAnglePitch);

  // Serial.println(" ");  

  //  serial plotter comparison
  // Serial.print(KalmanAngleRoll);
  // Serial.print(" ");
  // Serial.print(KalmanAnglePitch);
  // Serial.print(" ");
  // Serial.print(complementaryAngleRoll);
  // Serial.print(" ");
  // Serial.println(complementaryAnglePitch);

  while (micros() - LoopTimer < (t*1000000));
  {
    LoopTimer = micros();
  }
}
